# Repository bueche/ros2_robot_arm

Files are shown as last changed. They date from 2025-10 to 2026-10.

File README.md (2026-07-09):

# Ros2 Robot Arm and Balance PID Controller Using Koch v1.1 Follower

## Summary
The following repository has the source, resources, and instructions for building a robotic arm and its digital twin. The arm is based on a modified Koch V1.1 "follower arm" physical design (see [Robotis Koch v1.1 follower arm](https://robotis.us/koch-v1-1-low-cost-robot-arm-follower/)) and its powered by The Robot Operating System v2 [ROS2](https://github.com/ros2).  

(**NEW**) The current effort is focused on enabling this robotic arm to balance a cup containing a metal ball bearing. Balancing is a perennial challenge with robotics (as humanoid robots often fall at embarrassing times ;-)). The koch v1.1 hardware is a bit limited to explore all aspects of balance, but useful as a starter task. This is being 
accomplished by enhancing the robot with additinoal hardware (IMU sensor and inferencing camera) and software, including a Balance [PID controller](https://en.wikipedia.org/wiki/Proportional%E2%80%93integral%E2%80%93derivative_controller) (PID = Proportional–integral–derivative) and a vision ML model among other modules. [Learn more ..](./documentation/balance.md)

This branch supports Ros2 Jazzy (4.2+) and a combination with Humble for the ball bearing detection inferencing.

The details in this project include:
 - Fabrication and/or purchase, modification, and assembly of robotic parts (brackets, Dynamixel servos, and related circuit boards and sensors)
 - Testing and tuning of the physical robot
 - Creating, calibrating, and tuning of the robot arm digital twin (that runs in [rviz](https://docs.ros.org/en/jazzy/Tutorials/Intermediate/RViz/RViz-User-Guide/RViz-User-Guide.html)),
 - Refinement of ROS2-based software to support various actions of the robotic arm and the gathering of physical statistics (current, voltage, temperature, etc)
 - The development of the ML models for ball detection and the PID controller for for balance.

<p align="center">
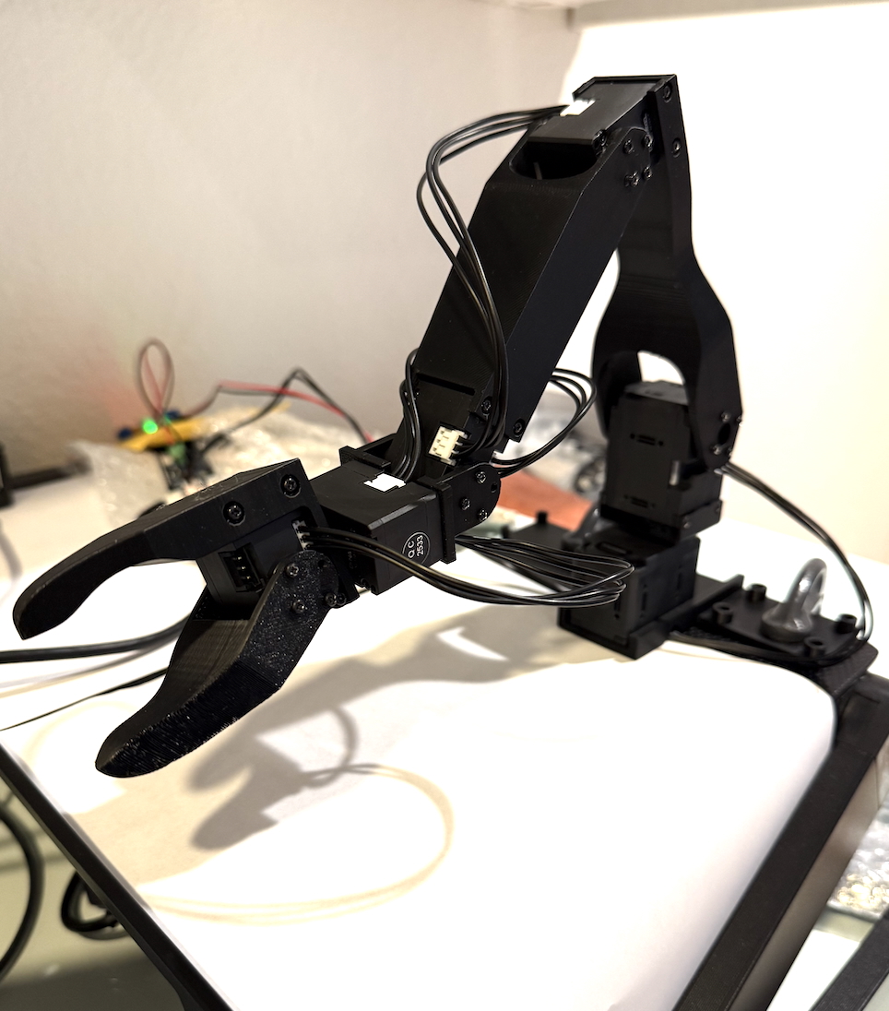
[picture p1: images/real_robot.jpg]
Real Robot Arm
  
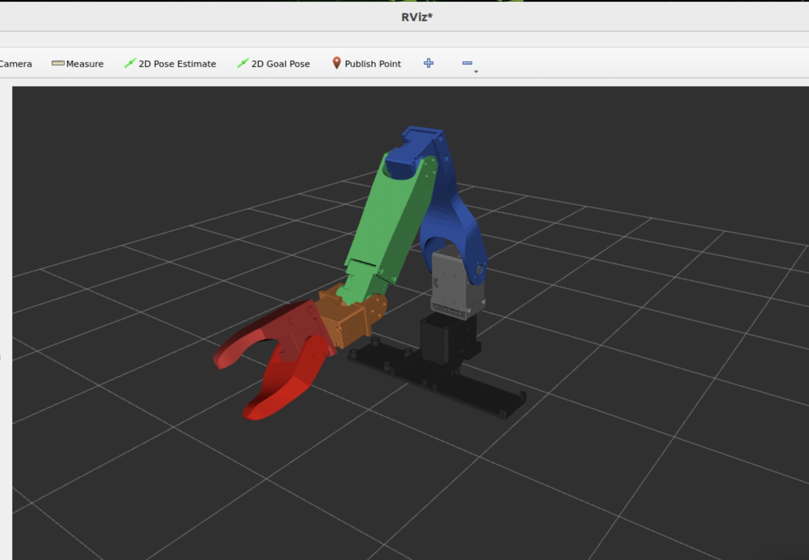
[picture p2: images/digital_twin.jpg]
The digital twin
  
</p>

The documentation for this repository covers the following:
- [Software Setup](./documentation/software_setup.md): how to create the docker envrionment and any additional setup commands. 
- [Hardware Setup](./documentation/hardware_setup.md): Although the setup of the koch_v11 physical robot (leader and follower arms) is partially documented ([Arm assembly by Jess Moss](https://www.youtube.com/watch?v=8nQIg9BwwTk)), those instructions lacked details on some of the required electrical setup. In addition, we are using different controller boards (e.g., Dynamixel OpenRB 150).
- [Firmware Setup and Configuration](./documentation/firmware.md): Notes on the firmware setup and configuration for the OpenRB 150, the servo motors, the current sensors, and the ESP32.
- [Notes on creating the digital twin](./documentation/digital_twin.md): A series of notes that cover the problems and solutions for creating the digital twin.
- [Launching the Physical Robot](./documentation/launching_physical.md) Steps involved in bringing up the physical robot.
- [Running the display only version of the Digital twin](./documentation/display_launch.md): This describes how to bring up the digital twin - either along side the physical robot or by itself as an rviz display-only flavor of the robot.
- [Pose Sequence Tools and Analysis](./documentation/utilities.md): Several tools are provided that drive the robot through a series of poses and analyze physical characteristics (position, temp, current, voltage, etc). This section also provides some analysis case studies that are of interest.
- **NEW** [Balancing a cup with the robotic arm ](./documentation/balance.md): These notes include detailed descriptions of the add-ons to the Koch v1.1 hardware (3D Inferencing camera and IMU) and software: PID related nodes and Machine Learning models for inferencing on the Camera and on an Nvidia Orin Nano.

<p align="center">
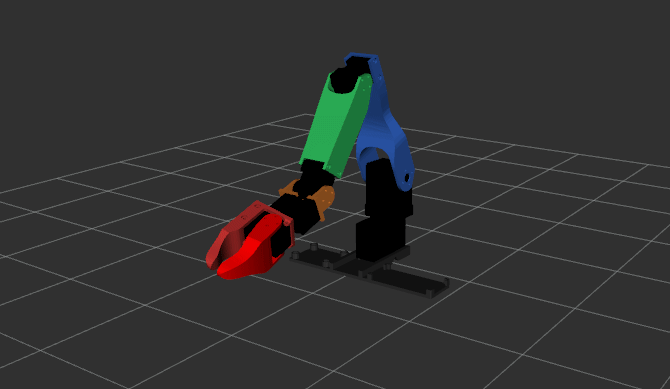
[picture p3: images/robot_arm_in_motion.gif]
Real Robot Arm
  
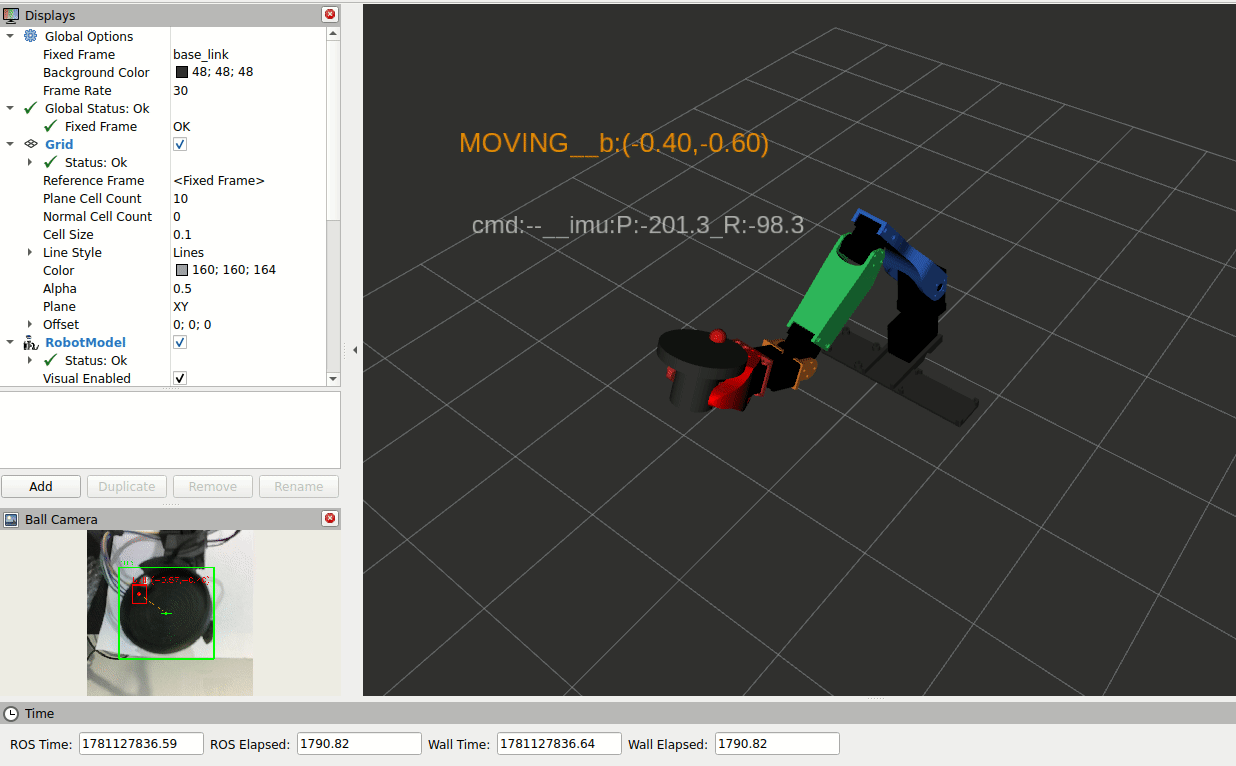
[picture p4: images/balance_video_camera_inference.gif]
balance video

</p>

Animations above:
1. The digital twin executing a series of poses that exercise all of the robotic joints.
2. The full rviz output showing a small excerpt of the pose and PID operations. The lower lefthand side is an bounding box annotated view of the camera (image after inferencing) and the right hand side 3D view shows the corresponding movement of the cup, ball, and robot. In this video 5 different tipping poses are set moving the ball bearing to one of the cup. Following each the balance pid controller kicks in and balances the ball within the cup.

## FAQ
### How can this repository be useful?
This repository can be of use to someone building robotics in several ways:
1. *Developers using the Koch V1.1 follower arm*: Although some of the design and operation of the Koch v1.1 robot arm is open source, a developer of it may encounter a number of gaps or issues when working with it. This repository should complement information and software from ROBOTIS and other sources. For example, we provide a  [koch v1.1 URDF](https://github.com/bueche/ros2_robot_arm/blob/main/writing_robot_description/urdf/koch_v11_arm_real.urdf) file that is configured and calibrated to provide a digital twin that matches the physical robot in appearance. In addition, we provide [complete and accurate wiring diagrams](https://github.com/bueche/ros2_robot_arm/blob/main/documentation/hardware_setup.md#electrical-notes) that detail how to co-exist the 12V and 5V Dynamixel servos in the same environment.
   
2. *Developers interested in PID controllers and balance*: Achieving balance in a robotics system has been a challenging research and development area. Humanoid robots still fall over regularly in critical demos. Although the koch v1.1 robot arm is limited in a number of ways the effort of getting it to balance a cup is a good starter task in this area.

3. *Developers integrating vision into their robotics system*: This is perhaps less challenging than achieving balance, but still difficult and covered in much detail. We explore inference on the camera vs. on an Nvidia Orin Nano.
 
4. *Developers wanting to pull more telemetry from Dynamixel servos in a ROS2 environment*: The ros2 interface for the Dynamixel servos is quite limited relative to the internal data it can pull (as compared with the Dynamixel Wizard tool). For example, one can't get a reading on the voltage seen by a servo, even though extra strain on the system could lead to an under-volt situation for the servos in series. We provide information on how to improve this for ros2 and how to set this up ([in code](https://github.com/bueche/ros2_robot_arm/blob/main/documentation/software_setup.md#dynamixel-software-changes)) and retrieve the values at runtime via ros2.

5. *Developers who are adapting robotic arms to ROS2 or not starting from a well defined kit*: ROBOTIS provides several full kits for someone getting started with robot arms that provide a good head start including this [Koch v1.1.](https://robotis.us/koch-v1-1-low-cost-robot-arm-follower/), [OMX AI manipulator](https://robotis.us/omx-ai-us/), [OMY AI manipulator](https://robotis.us/omy-ai3m/), and more. This project provides information for someone who is departing from an easy-to-assemble kit.

### What is a leader-follower robotic arm?
A leader-follower robotic arm system consists of two robotic manipulators where one arm (the leader) is manually controlled by a human operator, and the second arm (the follower) replicates those movements in real-time. It's essentially a form of bilateral teleoperation. In this project we are primarily focused on the follower arm.

### Why is this project focused on the follower?
In general leader arms are meant more for human manipulation as they define the poses that the follower will replicate. That limited operational scope for the leader means that its likely that the arm is under powered and/or has a design that is for human manipulation vs. automation. In this project we use the follower as the leader (to predefine poses and collect the measurements) albiet in a less automatic fashion. We also want to study the follower's load and physical characeteristics (e.g., temperature) as it repeatedly performs the activity. In addition, the cup balancing sub-project doesn't quite fit the leader/follower paradigm. 

## Upcoming sub-projects
### Upgrade of Nvidia Orin Nano to JetPack 7.2 with Jetson Linux 39.2
This upgrade to JetPack 7.2 with Jetson Linux 39.2 will allow this project to by-pass the inferencing on the camera and increase the frames per sec inferencing from 12 to 35 FPS. Aside from performance the benefit is an all Jazzy architecture with that approach.

### Extend the software to support the SO-arm101 and Feetech servos
This sub-project is about extending the software and hardware support to a different robotic arm the SO-ARM101 which is based on Feetech servos rather than Dynamixel servos. 

## Extend model to use 3D capabilities of OAK-D lite camera
Currently we are not using the 3D capabilities of the OAK-D lite camera due to its computational load on the camera. Once we have a Jazzy-based Nvidia inferencing stack, then this becomes something we can potentially leverage.

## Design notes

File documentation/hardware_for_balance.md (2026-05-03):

# Hardware for Cup Balancing Project

The additional hardware for this cup balancing portion of the project is identified in the [hardware section](./hardware_setup.md#balance-related-hardware). In this section we describe some key aspects of the two main additional components: the Luxonis Oak D camera and the IMU. 

## Camera: Luxonis OAK-D lite
In this section we discuss some points related to camera's and this application. 
- Introduction: As noted earlier the basic function of the camera is to track the movement and coordiates of the ball within the cup. It does this using hardware and software built into the camera. The camera is actually able to run a special trained ML model that has been built to recognize the cup and the ball moving in the robot environment. The goal is to get the ball to the middle of the cup and the ball is typically on the perimeter of the cup. Its current coordinates need to determined accurately and with low latency. 

<p align="center">
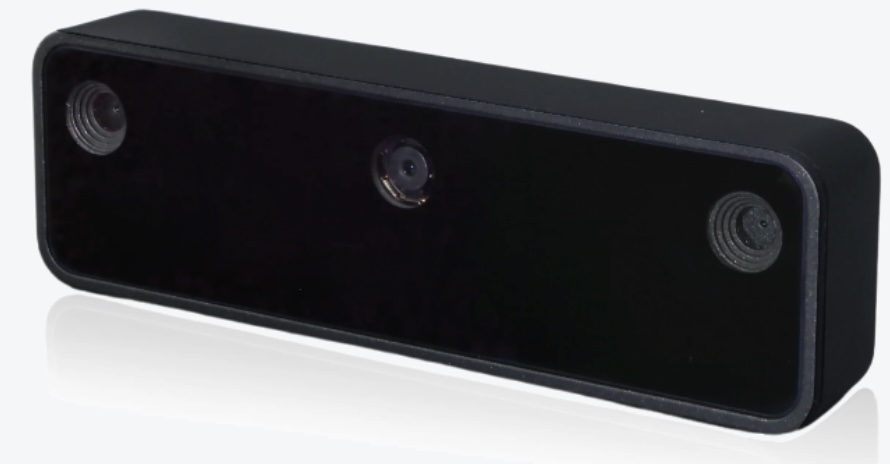
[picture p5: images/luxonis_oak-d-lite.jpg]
luxonis camera
  
</p>

- Inferencing camera vs. basic USB camera: 
  - *Why use an inferencing camera?* The basic flow requires that images are fed to a model which detects the cup and ball and provides the coordinates of the ball within the cup. The theoretically benefit of the inferencing camera is its ability to avoid having the transport those images in a high frame rate to the inferencing software running on a different host / processor. Instead the inferencing camera can do the detection locally and only report coordinates. It is ideal if all you have is a Raspberry Pi, but since we also have access to an Nvidia Orin Nano we have other options. We will implement the approach of using the Nvidia Orin Nano for inferencing, but have not done so as of yet. 
  
  Still, using the Nano as the camera attachmentWe did find that some additional tuning is required due to the fact that the Orin Nano (at least this version) only exposes USB-2 ports.
  ```
  nvidia-nano:~/robot_ws/src$ lsusb -t
   /:  Bus 02.Port 1: Dev 1, Class=root_hub, Driver=tegra-xusb/4p, 10000M
          |__ Port 1: Dev 2, If 0, Class=Hub, Driver=hub/4p, 10000M
   /:  Bus 01.Port 1: Dev 1, Class=root_hub, Driver=tegra-xusb/4p, 480M
          |__ Port 1: Dev 54, If 0, Class=Vendor Specific Class, Driver=, 480M <---- dev 54 at 480Mbps
          |__ Port 2: Dev 2, If 0, Class=Hub, Driver=hub/4p, 480M
          |__ Port 3: Dev 3, If 0, Class=Wireless, Driver=rtk_btusb, 12M
          |__ Port 3: Dev 3, If 1, Class=Wireless, Driver=rtk_btusb, 12M
  nvidia-nano:~/robot_ws/src$ lsusb
  Bus 002 Device 002: ID 0bda:0489 Realtek Semiconductor Corp. 4-Port USB 3.0 Hub
  Bus 002 Device 001: ID 1d6b:0003 Linux Foundation 3.0 root hub
  Bus 001 Device 003: ID 13d3:3549 IMC Networks Bluetooth Radio
  Bus 001 Device 002: ID 0bda:5489 Realtek Semiconductor Corp. 4-Port USB 2.0 Hub
  Bus 001 Device 054: ID 03e7:2485 Intel Movidius MyriadX <---------------- Luxonis Oak-D lite device 54
  Bus 001 Device 001: ID 1d6b:0002 Linux Foundation 2.0 root hub
  ```

  - *What is the USB-2 vs USB-3 bandwidth?*
    | Standard | Theoretical| Practical (60-70%) | 
    |----------|------------|--------------------|
    | USB 2.0 High Speed | 480 Mbps | ~300 Mbps | 
    | USB 3.0 SuperSpeed | 5000 Mbps | ~3000 Mbps |

  - *But is USB-2 a bottleneck?* With raw frames it will be.  
  - *What is an alternative approach to Camera inferencing?* Alternatively, 
  
  - We are motivated to reduce the image transport bandwidth partly because of Nvidia Orin Nano's USB-2 limitation. 
  - *Why does USB-2 have insufficient bandwidth for streaming video for this application?* The raw image bandwidth formula can be put as follows:
  ```
  bandwidth = image_width × image_height × channels × bytes_per_channel × frames_per_sec x jpeg_compression_factor
  ```
  - where:
    - image_width x image_height define the pixels/frame.
    - Ideally, we could process at least 30 frames per sec to ensure smooth/fluid movement as perceived by our eyes, but this rate has a signficant impact on bandwidth.
    - there are 3 channels of  ....
    - the compression factor is 1/15
  - USB bandwidth:
    | Standard | Theoretical| Practical (60-70%) | 
    |----------|------------|--------------------|
    | USB 2.0 High Speed | 480 Mbps | ~300 Mbps | 
    | USB 3.0 SuperSpeed | 5000 Mbps | ~3000 Mbps |

- Camera inferencing vs. Nvidia inferencing
  - Now we have been able to achieve 12 frames per sec cup/ball inferencing using the Luxonis OAK-D lite and a 640x640 YOLOv8n ML model. This is pretty close to with  [benchmark results for this device](https://docs.luxonis.com/hardware/platform/rvc/rvc2/) which reached 14.3 frames per sec inferencing. 
  - The reported inference latency in that Luxonis benchmark was 120 msec. We expect to get significantly better latency using Nvidia as long as the USB-2 pipe doesn't become a bottleneck when we leverage the  H.264 or H.265 codecs.
  
- 3D camera vs. 2D camera
  - The Luxonis OAK-D lite is also a 3D camera. We have turned off that capability due to the processing needs of inferencing, but will re-enable it when inferencing shifts to the Nvidia Orin Nano.

## IMU
Some discussion points on IMU:
- IMU level vs. ball level
- IMU calibration challenges
- IMU wiring impact on servo accuracy and mobility 
- also reference the Dynamixel servo tuning section

<p align="center">
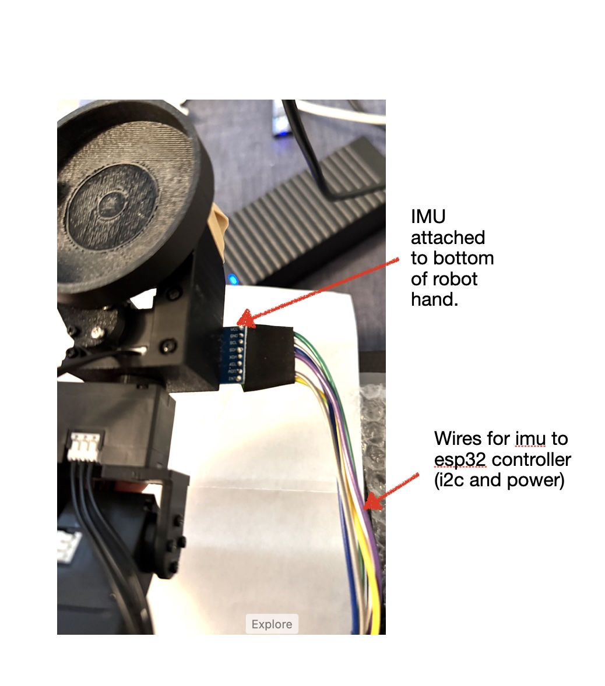
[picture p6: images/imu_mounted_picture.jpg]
imu mounted on bottom of hand
  
</p>

Discussion on the Koch v1.1 and:
- its ability to hold a cup steady
- its ability to hold a cup + ball + IMU + wires for IMU

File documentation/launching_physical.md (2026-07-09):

# Launching the Physical Robot 

Once the software and hardware envionment has been setup with the one-time setup items, then a few additional commands are needed to bring up the physical robot and its digital twin in Rviz2.

## Table of Contents
- [Ensure that the USB port can be accessed](#ensure-that-the-usb-port-can-be-accessed)
- [Launching the basic robot](#launch-the-robot-via-ros2)
- [Launching the robot for balancing activity](#launcing-the-robot-for-balancing-activity)

## Ensure that the USB port can be accessed
The code assumes the port is `/dev/ttyUSB0`. On a Raspberry Pi5 on Ubuntu the device is either `/dev/ttyACM0` or `/dev/ttyACM0`.
If the there is no ttyUSB0 then create a soft link to it.
On ubuntu:

```bash
$ ls -lt /dev/tty* | head -5
crw-rw-rw- 1 root   tty       5,   0 Dec 24 10:44 /dev/tty
crw-rw---- 1 root   dialout 166,   0 Dec 24 10:43 /dev/ttyACM0   
crw--w---- 1 bueche tty       4,   2 Nov 10 14:28 /dev/tty2
crw------- 1 root   root      3, 167 Nov 10 14:27 /dev/ttyz7
rpi5:~$
rpi5:~$ sudo ln -sf /dev/ttyACM0 /dev/ttyUSB0
rpi5:~$
rpi5:~$ ls -lt /dev/tty* | head -5
crw-rw-rw- 1 root   tty       5,   0 Dec 24 10:44 /dev/tty
crw-rw---- 1 root   dialout 166,   0 Dec 24 10:43 /dev/ttyACM0   
lrwxrwxrwx 1 root   root          12 Dec 21 18:35 /dev/ttyUSB0 -> /dev/ttyACM0 # SOFT LINK CREATED
crw--w---- 1 bueche tty       4,   2 Nov 10 14:28 /dev/tty2
crw------- 1 root   root      3, 167 Nov 10 14:27 /dev/ttyz7
```
But it still needs to be readable and writable by other.

On ubuntu:
```bash
rpi5:~$ ls -lt /dev/tty* | head -5
crw-rw-rw- 1 root   tty       5,   0 Dec 24 10:44 /dev/tty
crw-rw---- 1 root   dialout 166,   0 Dec 24 10:43 /dev/ttyACM0   # NOTE: IS NOT rw BY other
lrwxrwxrwx 1 root   root          12 Dec 21 18:35 /dev/ttyUSB0 -> /dev/ttyACM0
crw--w---- 1 bueche tty       4,   2 Nov 10 14:28 /dev/tty2
crw------- 1 root   root      3, 167 Nov 10 14:27 /dev/ttyz7

rpi5:~$ sudo chmod ugo+rw /dev/ttyACM0

rpi5:~$ ls -lt /dev/tty* | head -5
crw-rw-rw- 1 root   tty       5,   0 Dec 24 11:44 /dev/tty
crw-rw-rw- 1 root   dialout 166,   0 Dec 24 10:47 /dev/ttyACM0 # NOTES: NOW rw BY other
lrwxrwxrwx 1 root   root          12 Dec 21 18:35 /dev/ttyUSB0 -> /dev/ttyACM0
crw--w---- 1 bueche tty       4,   2 Nov 10 14:28 /dev/tty2
crw------- 1 root   root      3, 167 Nov 10 14:27 /dev/ttyz7

```

## Launch the robot via ros2
```bash
rpi5:~/$ 
rpi5:~/$ pwd
/home/ubuntu/
rpi5:~/$ cd robot_ws
rpi5:~/robot_ws$ source ./install/setup.bash
rpi5:~/robot_ws$ ros2 launch writing_robot_description koch_v11_real_robot.launch.py
```
This will launch the ros2 robot software. The full example output is shown below. We comment on some of parts below.

```
$ ros2 launch writing_robot_description koch_v11_real_robot.launch.py
[INFO] [launch]: All log files can be found below /home/ubuntu/.ros/log/2026-03-01-23-27-25-361593-bueche-rpi5-6584
[INFO] [launch]: Default logging verbosity is set to INFO
[INFO] [robot_state_publisher-1]: process started with pid [6587]
[INFO] [ros2_control_node-2]: process started with pid [6588]
[ros2_control_node-2] [INFO] [1772407645.679930506] [controller_manager]: Using Steady (Monotonic) clock for triggering controller manager cycles.
[ros2_control_node-2] [INFO] [1772407645.686064407] [controller_manager]: Subscribing to '/robot_description' topic for robot description.
[ros2_control_node-2] [INFO] [1772407645.690637597] [controller_manager]: update rate is 100 Hz
[ros2_control_node-2] [INFO] [1772407645.690681912] [controller_manager]: Overruns handling is : enabled
[ros2_control_node-2] [INFO] [1772407645.690695190] [controller_manager]: Spawning controller_manager RT thread with scheduler priority: 50
[ros2_control_node-2] [WARN] [1772407645.690820061] [controller_manager]: Could not enable FIFO RT scheduling policy: with error number <1>(Operation not permitted). See [https://control.ros.org/master/doc/ros2_control/controller_manager/doc/userdoc.html] for details on how to enable realtime scheduling.
[robot_state_publisher-1] [WARN] [1772407645.709807044] [kdl_parser]: The root link base_link has an inertia specified in the URDF, but KDL does not support a root link with an inertia.  As a workaround, you can add an extra dummy link to your URDF.
[robot_state_publisher-1] [INFO] [1772407645.710002990] [robot_state_publisher]: Robot initialized
[ros2_control_node-2] [INFO] [1772407645.781235642] [controller_manager]: Received robot description from topic.
[ros2_control_node-2] [INFO] [1772407645.787500822] [controller_manager]: Loading hardware 'koch_v11_system' 
[ros2_control_node-2] [INFO] [1772407645.802065987] [controller_manager]: Loaded hardware 'koch_v11_system' from plugin 'dynamixel_hardware_interface/DynamixelHardware'
[ros2_control_node-2] [INFO] [1772407645.803658458] [controller_manager]: Initialize hardware 'koch_v11_system' 
[ros2_control_node-2] transmission_to_joint_matrix_ 
[ros2_control_node-2] [0][0] 1.000000, [0][1] 0.000000, [0][2] 0.000000, [0][3] 0.000000, [0][4] 0.000000, [0][5] 0.000000, 
[ros2_control_node-2] [1][0] 0.000000, [1][1] 1.000000, [1][2] 0.000000, [1][3] 0.000000, [1][4] 0.000000, [1][5] 0.000000, 
[ros2_control_node-2] [2][0] 0.000000, [2][1] 0.000000, [2][2] 1.000000, [2][3] 0.000000, [2][4] 0.000000, [2][5] 0.000000, 
[ros2_control_node-2] [3][0] 0.000000, [3][1] 0.000000, [3][2] 0.000000, [3][3] 1.000000, [3][4] 0.000000, [3][5] 0.000000, 
[ros2_control_node-2] [4][0] 0.000000, [4][1] 0.000000, [4][2] 0.000000, [4][3] 0.000000, [4][4] 1.000000, [4][5] 0.000000, 
[ros2_control_node-2] [5][0] 0.000000, [5][1] 0.000000, [5][2] 0.000000, [5][3] 0.000000, [5][4] 0.000000, [5][5] 1.000000, 
[ros2_control_node-2] joint_to_transmission_matrix_ 
[ros2_control_node-2] [0][0] 1.000000, [0][1] 0.000000, [0][2] 0.000000, [0][3] 0.000000, [0][4] 0.000000, [0][5] 0.000000, 
[ros2_control_node-2] [1][0] 0.000000, [1][1] 1.000000, [1][2] 0.000000, [1][3] 0.000000, [1][4] 0.000000, [1][5] 0.000000, 
[ros2_control_node-2] [2][0] 0.000000, [2][1] 0.000000, [2][2] 1.000000, [2][3] 0.000000, [2][4] 0.000000, [2][5] 0.000000, 
[ros2_control_node-2] [3][0] 0.000000, [3][1] 0.000000, [3][2] 0.000000, [3][3] 1.000000, [3][4] 0.000000, [3][5] 0.000000, 
[ros2_control_node-2] [4][0] 0.000000, [4][1] 0.000000, [4][2] 0.000000, [4][3] 0.000000, [4][4] 1.000000, [4][5] 0.000000, 
[ros2_control_node-2] [5][0] 0.000000, [5][1] 0.000000, [5][2] 0.000000, [5][3] 0.000000, [5][4] 0.000000, [5][5] 1.000000, 
[ros2_control_node-2] [INFO] [1772407645.818822442] [dynamixel_hardware_interface]: error_timeout_ms parameter not found, using default value of 500ms
[ros2_control_node-2] [INFO] [1772407645.818887646] [dynamixel_hardware_interface]: If there is a torque enabled Dynamixel, the program will be terminated. Set 'disable_torque_at_init' parameter to 'true' to disable torque at initialization.
[ros2_control_node-2] [INFO] [1772407645.818910035] [dynamixel_hardware_interface]: port_name /dev/ttyUSB0 / baudrate 1000000
[ros2_control_node-2] Dynamixel Information File List.
[ros2_control_node-2] num: 30, name: mx_28.model
[ros2_control_node-2] num: 220, name: omy_hat.model
[ros2_control_node-2] num: 230, name: omy_end.model
[ros2_control_node-2] num: 231, name: omy_end_rh_p12_rn.model
[ros2_control_node-2] num: 260, name: hx5_d20_rr.model
[ros2_control_node-2] num: 261, name: hx5_d20_rl.model
[ros2_control_node-2] num: 6001, name: hx5_d20_r_synctable_1_device_1.model
[ros2_control_node-2] num: 6002, name: hx5_d20_r_synctable_1_device_2.model
[ros2_control_node-2] num: 6003, name: hx5_d20_r_synctable_1_device_3.model
[ros2_control_node-2] num: 6004, name: hx5_d20_r_synctable_1_device_4.model
[ros2_control_node-2] num: 6005, name: hx5_d20_r_synctable_1_device_5.model
[ros2_control_node-2] num: 6006, name: hx5_d20_r_synctable_2_device_1.model
[ros2_control_node-2] num: 6007, name: hx5_d20_r_synctable_2_device_2.model
[ros2_control_node-2] num: 6008, name: hx5_d20_r_synctable_2_device_3.model
[ros2_control_node-2] num: 6009, name: hx5_d20_r_synctable_2_device_4.model
[ros2_control_node-2] num: 6010, name: hx5_d20_r_synctable_2_device_5.model
[ros2_control_node-2] num: 6011, name: hx5_d20_r_synctable_3_device_1.model
[ros2_control_node-2] num: 6012, name: hx5_d20_r_synctable_3_device_2.model
[ros2_control_node-2] num: 6013, name: hx5_d20_r_synctable_3_device_3.model
[ros2_control_node-2] num: 6014, name: hx5_d20_r_synctable_3_device_4.model
[ros2_control_node-2] num: 6015, name: hx5_d20_r_synctable_3_device_5.model
[ros2_control_node-2] num: 6016, name: hx5_d20_r_synctable_4_device_1.model
[ros2_control_node-2] num: 6017, name: hx5_d20_r_synctable_4_device_2.model
[ros2_control_node-2] num: 6018, name: hx5_d20_r_synctable_4_device_3.model
[ros2_control_node-2] num: 6019, name: hx5_d20_r_synctable_4_device_4.model
[ros2_control_node-2] num: 6020, name: hx5_d20_r_synctable_4_device_5.model
[ros2_control_node-2] num: 6021, name: hx5_d20_r_synctable_5_device_1.model
[ros2_control_node-2] num: 6022, name: hx5_d20_r_synctable_5_device_2.model
[ros2_control_node-2] num: 6023, name: hx5_d20_r_synctable_5_device_3.model
[ros2_control_node-2] num: 6024, name: hx5_d20_r_synctable_5_device_4.model
[ros2_control_node-2] num: 6025, name: hx5_d20_r_synctable_5_device_5.model
[ros2_control_node-2] num: 311, name: mx_64.model
[ros2_control_node-2] num: 321, name: mx_106.model
[ros2_control_node-2] num: 350, name: xl320.model
[ros2_control_node-2] num: 536, name: sensorxel_joy.model
[ros2_control_node-2] num: 537, name: ffw_g40_imu.model
[ros2_control_node-2] num: 600, name: sensorxel_joy.model
[ros2_control_node-2] num: 601, name: ffw_g10_led.model
[ros2_control_node-2] num: 602, name: ffw_g10_rcu.model
[ros2_control_node-2] num: 620, name: ffw_sg2_steer_1.model
[ros2_control_node-2] num: 621, name: ffw_sg2_steer_2.model
[ros2_control_node-2] num: 622, name: ffw_sg2_steer_3.model
[ros2_control_node-2] num: 623, name: ffw_sg2_drive_1.model
[ros2_control_node-2] num: 624, name: ffw_sg2_drive_2.model
[ros2_control_node-2] num: 625, name: ffw_sg2_drive_3.model
[ros2_control_node-2] num: 1000, name: xh430_w350.model
[ros2_control_node-2] num: 1001, name: xd430_t350.model
[ros2_control_node-2] num: 1010, name: xh430_w210.model
[ros2_control_node-2] num: 1011, name: xd430_t210.model
[ros2_control_node-2] num: 1020, name: xm430_w350.model
[ros2_control_node-2] num: 1030, name: xm430_w210.model
[ros2_control_node-2] num: 1040, name: xh430_v350.model
[ros2_control_node-2] num: 1050, name: xh430_v210.model
[ros2_control_node-2] num: 1060, name: xl430_w250.model
[ros2_control_node-2] num: 1070, name: xc430_w150.model
[ros2_control_node-2] num: 1070, name: xc430_w150.model
[ros2_control_node-2] num: 1080, name: xc430_w240.model
[ros2_control_node-2] num: 1080, name: xc430_w240.model
[ros2_control_node-2] num: 1090, name: 2xl430_w250.model
[ros2_control_node-2] num: 1100, name: xh540_w270.model
[ros2_control_node-2] num: 1101, name: xd540_t270.model
[ros2_control_node-2] num: 1110, name: xh540_w150.model
[ros2_control_node-2] num: 1111, name: xd540_t150.model
[ros2_control_node-2] num: 1120, name: xm540_w270.model
[ros2_control_node-2] num: 1130, name: xm540_w150.model
[ros2_control_node-2] num: 1140, name: xh540_v270.model
[ros2_control_node-2] num: 1150, name: xh540_v150.model
[ros2_control_node-2] num: 1160, name: 2xc430_w250.model
[ros2_control_node-2] num: 1170, name: xw540_t260.model
[ros2_control_node-2] num: 1180, name: xw540_t140.model
[ros2_control_node-2] num: 1190, name: xl330_m077.model
[ros2_control_node-2] num: 1200, name: xl330_m288.model
[ros2_control_node-2] num: 1210, name: xc330_t181.model
[ros2_control_node-2] num: 1220, name: xc330_t288.model
[ros2_control_node-2] num: 1230, name: xc330_m181.model
[ros2_control_node-2] num: 1240, name: xc330_m288.model
[ros2_control_node-2] num: 1270, name: xw430_t333.model
[ros2_control_node-2] num: 1310, name: xw540_h260.model
[ros2_control_node-2] num: 1700, name: xc335_t332.model
[ros2_control_node-2] num: 2000, name: ph42_020_s300.model
[ros2_control_node-2] num: 2010, name: ph54_100_s500.model
[ros2_control_node-2] num: 2020, name: ph54_200_s500.model
[ros2_control_node-2] num: 2100, name: pm42_010_s260.model
[ros2_control_node-2] num: 2110, name: pm54_040_s250.model
[ros2_control_node-2] num: 2120, name: pm54_060_s250.model
[ros2_control_node-2] num: 4000, name: ym070_210_m001.model
[ros2_control_node-2] num: 4010, name: ym070_210_b001.model
[ros2_control_node-2] num: 4020, name: ym070_210_r051.model
[ros2_control_node-2] num: 4030, name: ym070_210_r099.model
[ros2_control_node-2] num: 4040, name: ym070_210_a051.model
[ros2_control_node-2] num: 4050, name: ym070_210_a099.model
[ros2_control_node-2] num: 4120, name: ym080_230_m001.model
[ros2_control_node-2] num: 4130, name: ym080_230_b001.model
[ros2_control_node-2] num: 4140, name: ym080_230_r051.model
[ros2_control_node-2] num: 4150, name: ym080_230_r099.model
[ros2_control_node-2] num: 4160, name: ym080_230_a051.model
[ros2_control_node-2] num: 4170, name: ym080_230_a099.model
[ros2_control_node-2] num: 35074, name: rh_p12_rn.model
[ros2_control_node-2] num: 43289, name: m42_10_s260_ra.model
[ros2_control_node-2] num: 46097, name: m54_40_s250_ra.model
[ros2_control_node-2] num: 46353, name: m54_60_s250_ra.model
[ros2_control_node-2] num: 51201, name: h42_20_s300_ra.model
[ros2_control_node-2] num: 53769, name: h54_100_s500_ra.model
[ros2_control_node-2] num: 54025, name: h54_200_s500_ra.model
[ros2_control_node-2] [INFO] [1772407645.819989522] [dynamixel_hardware_interface]: $$$$$$$$$$$$$$$$$$$$$$$$$$$$$$$$$$$$$$$$
[ros2_control_node-2] [INFO] [1772407645.820040651] [dynamixel_hardware_interface]: $$$$$ Init Dxl Comm Port
[ros2_control_node-2] Succeeded to open the port [/dev/ttyUSB0]! (attempt 1/5)
[ros2_control_node-2] Succeeded to change the baudrate [1000000]!
[ros2_control_node-2] [comm_id:001][ID:001] Request ping	 - Ping succeeded. Dynamixel model number : 1060 (xl430_w250.model)
[ros2_control_node-2] [InitTorqueStates][comm_id:001][ID:001] Current torque state: OFF
[ros2_control_node-2] [comm_id:002][ID:002] Request ping	 - Ping succeeded. Dynamixel model number : 1060 (xl430_w250.model)
[ros2_control_node-2] [InitTorqueStates][comm_id:002][ID:002] Current torque state: OFF
[ros2_control_node-2] [comm_id:003][ID:003] Request ping	 - Ping succeeded. Dynamixel model number : 1200 (xl330_m288.model)
[ros2_control_node-2] [InitTorqueStates][comm_id:003][ID:003] Current torque state: OFF
[ros2_control_node-2] [comm_id:004][ID:004] Request ping	 - Ping succeeded. Dynamixel model number : 1200 (xl330_m288.model)
[ros2_control_node-2] [InitTorqueStates][comm_id:004][ID:004] Current torque state: OFF
[ros2_control_node-2] [comm_id:005][ID:005] Request ping	 - Ping succeeded. Dynamixel model number : 1200 (xl330_m288.model)
[ros2_control_node-2] [InitTorqueStates][comm_id:005][ID:005] Current torque state: OFF
[ros2_control_node-2] [comm_id:006][ID:006] Request ping	 - Ping succeeded. Dynamixel model number : 1190 (xl330_m077.model)
[ros2_control_node-2] [InitTorqueStates][comm_id:006][ID:006] Current torque state: OFF
[ros2_control_node-2] [INFO] [1772407645.889421591] [dynamixel_hardware_interface]: $$$$$ Init Dxl Read Items
[ros2_control_node-2] Dynamixel Read Type : bulk read
[ros2_control_node-2] ID : 1	Read items : 	Present Position	Present Velocity	Present Load	Present Temperature	Present Input Voltage
[ros2_control_node-2] ID : 2	Read items : 	Present Position	Present Velocity	Present Load	Present Temperature	Present Input Voltage
[ros2_control_node-2] ID : 3	Read items : 	Present Position	Present Velocity	Present Current	Present Temperature	Present Input Voltage
[ros2_control_node-2] ID : 4	Read items : 	Present Position	Present Velocity	Present Current	Present Temperature	Present Input Voltage
[ros2_control_node-2] ID : 5	Read items : 	Present Position	Present Velocity	Present Current	Present Temperature	Present Input Voltage
[ros2_control_node-2] ID : 6	Read items : 	Present Position	Present Velocity	Present Current	Present Temperature	Present Input Voltage
[ros2_control_node-2] [ID:001] Add Indirect Address Read Item : [Present Position]
[ros2_control_node-2] [ID:001] Add Indirect Address Read Item : [Present Velocity]
[ros2_control_node-2] [ID:001] Add Indirect Address Read Item : [Present Load]
[ros2_control_node-2] [ID:001] Add Indirect Address Read Item : [Present Temperature]
[ros2_control_node-2] [ID:001] Add Indirect Address Read Item : [Present Input Voltage]
[ros2_control_node-2] [ID:002] Add Indirect Address Read Item : [Present Position]
[ros2_control_node-2] [ID:002] Add Indirect Address Read Item : [Present Velocity]
[ros2_control_node-2] [ID:002] Add Indirect Address Read Item : [Present Load]
[ros2_control_node-2] [ID:002] Add Indirect Address Read Item : [Present Temperature]
[ros2_control_node-2] [ID:002] Add Indirect Address Read Item : [Present Input Voltage]
[ros2_control_node-2] [ID:003] Add Indirect Address Read Item : [Present Position]
[ros2_control_node-2] [ID:003] Add Indirect Address Read Item : [Present Velocity]
[ros2_control_node-2] [ID:003] Add Indirect Address Read Item : [Present Current]
[ros2_control_node-2] [ID:003] Add Indirect Address Read Item : [Present Temperature]
[ros2_control_node-2] [ID:003] Add Indirect Address Read Item : [Present Input Voltage]
[ros2_control_node-2] [ID:004] Add Indirect Address Read Item : [Present Position]
[ros2_control_node-2] [ID:004] Add Indirect Address Read Item : [Present Velocity]
[ros2_control_node-2] [ID:004] Add Indirect Address Read Item : [Present Current]
[ros2_control_node-2] [ID:004] Add Indirect Address Read Item : [Present Temperature]
[ros2_control_node-2] [ID:004] Add Indirect Address Read Item : [Present Input Voltage]
[ros2_control_node-2] [ID:005] Add Indirect Address Read Item : [Present Position]
[ros2_control_node-2] [ID:005] Add Indirect Address Read Item : [Present Velocity]
[ros2_control_node-2] [ID:005] Add Indirect Address Read Item : [Present Current]
[ros2_control_node-2] [ID:005] Add Indirect Address Read Item : [Present Temperature]
[ros2_control_node-2] [ID:005] Add Indirect Address Read Item : [Present Input Voltage]
[ros2_control_node-2] [ID:006] Add Indirect Address Read Item : [Present Position]
[ros2_control_node-2] [ID:006] Add Indirect Address Read Item : [Present Velocity]
[ros2_control_node-2] [ID:006] Add Indirect Address Read Item : [Present Current]
[ros2_control_node-2] [ID:006] Add Indirect Address Read Item : [Present Temperature]
[ros2_control_node-2] [ID:006] Add Indirect Address Read Item : [Present Input Voltage]
[ros2_control_node-2] set fast bulk read (indirect addr) : addr 634, size 13
[ros2_control_node-2] set fast bulk read (indirect addr) : addr 634, size 13
[ros2_control_node-2] set fast bulk read (indirect addr) : addr 230, size 13
[ros2_control_node-2] set fast bulk read (indirect addr) : addr 230, size 13
[ros2_control_node-2] set fast bulk read (indirect addr) : addr 230, size 13
[ros2_control_node-2] set fast bulk read (indirect addr) : addr 230, size 13
[ros2_control_node-2] [ID:001] Add BulkRead item : [Indirect Item Data][634][13]
[ros2_control_node-2] [ID:002] Add BulkRead item : [Indirect Item Data][634][13]
[ros2_control_node-2] [ID:003] Add BulkRead item : [Indirect Item Data][230][13]
[ros2_control_node-2] [ID:004] Add BulkRead item : [Indirect Item Data][230][13]
[ros2_control_node-2] [ID:005] Add BulkRead item : [Indirect Item Data][230][13]
[ros2_control_node-2] [ID:006] Add BulkRead item : [Indirect Item Data][230][13]
[ros2_control_node-2] FastBulkRead handler set up successfully.
[ros2_control_node-2] Success to set BulkRead handler using indirect address
[ros2_control_node-2] [INFO] [1772407646.032963679] [dynamixel_hardware_interface]: $$$$$ Init Dxl Write Items
[ros2_control_node-2] Dynamixel Write Type : sync write
[ros2_control_node-2] ID : 1, 2, 3, 4, 5, 6, 
[ros2_control_node-2] Write items : 	Goal Position
[ros2_control_node-2] set sync write (indirect addr) : addr 224, size 4
[ros2_control_node-2] Success to set SyncWrite handler using indirect address
[ros2_control_node-2] [INFO] [1772407646.088268549] [controller_manager]: Successful initialization of hardware 'koch_v11_system'
[ros2_control_node-2] [INFO] [1772407646.089759389] [resource_manager]: 'configure' hardware 'koch_v11_system' 
[ros2_control_node-2] [INFO] [1772407646.089791723] [resource_manager]: Successful 'configure' of hardware 'koch_v11_system'
[ros2_control_node-2] [INFO] [1772407646.089814186] [resource_manager]: 'activate' hardware 'koch_v11_system' 
[ros2_control_node-2] [INFO] [1772407646.094021670] [dynamixel_hardware_interface]: Sync joint state to command (joint: shoulder_pan, position, 1.56313 <- position, 1.56313
[ros2_control_node-2] [INFO] [1772407646.094076893] [dynamixel_hardware_interface]: Sync joint state to command (joint: shoulder_lift, position, 2.71515 <- position, 2.71515
[ros2_control_node-2] [INFO] [1772407646.094095541] [dynamixel_hardware_interface]: Sync joint state to command (joint: elbow_flex, position, 1.77482 <- position, 1.77482
[ros2_control_node-2] [INFO] [1772407646.094112671] [dynamixel_hardware_interface]: Sync joint state to command (joint: wrist_flex, position, 0.895845 <- position, 0.895845
[ros2_control_node-2] [INFO] [1772407646.094128745] [dynamixel_hardware_interface]: Sync joint state to command (joint: wrist_roll, position, 1.56159 <- position, 1.56159
[ros2_control_node-2] [INFO] [1772407646.094144930] [dynamixel_hardware_interface]: Sync joint state to command (joint: pen_holder, position, 1.62142 <- position, 1.62142
[ros2_control_node-2] [INFO] [1772407646.094361209] [dynamixel_hardware_interface]: Enabling torque for Dynamixels
[ros2_control_node-2] [comm_id:001][ID:001] Torque ON
[ros2_control_node-2] [comm_id:002][ID:002] Torque ON
[ros2_control_node-2] [comm_id:003][ID:003] Torque ON
[ros2_control_node-2] [comm_id:004][ID:004] Torque ON
[ros2_control_node-2] [comm_id:005][ID:005] Torque ON
[ros2_control_node-2] [comm_id:006][ID:006] Torque ON
[ros2_control_node-2] [INFO] [1772407646.108393835] [dynamixel_hardware_interface]: Dynamixel Hardware Start!
[ros2_control_node-2] [INFO] [1772407646.108474039] [resource_manager]: Successful 'activate' of hardware 'koch_v11_system'
[ros2_control_node-2] [INFO] [1772407646.108612113] [controller_manager]: Registering statistics for : koch_v11_system
[ros2_control_node-2] [INFO] [1772407646.108785466] [controller_manager]: Resource Manager has been successfully initialized. Starting Controller Manager services...
[INFO] [spawner-3]: process started with pid [6624]
[spawner-3] [INFO] [1772407648.214204665] [spawner_joint_state_broadcaster]: waiting for service /controller_manager/list_controllers to become available...
[ros2_control_node-2] [INFO] [1772407648.222263297] [controller_manager]: Loading controller : 'joint_state_broadcaster' of type 'joint_state_broadcaster/JointStateBroadcaster'
[ros2_control_node-2] [INFO] [1772407648.222330113] [controller_manager]: Loading controller 'joint_state_broadcaster'
[ros2_control_node-2] [INFO] [1772407648.238686880] [controller_manager]: Controller 'joint_state_broadcaster' node arguments: --ros-args --params-file /tmp/launch_params_yroe8zdt 
[spawner-3] [INFO] [1772407648.267153504] [spawner_joint_state_broadcaster]: Loaded joint_state_broadcaster
[ros2_control_node-2] [INFO] [1772407648.269032328] [controller_manager]: Configuring controller: 'joint_state_broadcaster'
[ros2_control_node-2] [INFO] [1772407648.269240977] [joint_state_broadcaster]: 'joints' or 'interfaces' parameter is empty. All available state interfaces will be published
[ros2_control_node-2] [INFO] [1772407648.287854144] [controller_manager]: Activating controllers: [ joint_state_broadcaster ]
[ros2_control_node-2] [INFO] [1772407648.295436664] [controller_manager]: Successfully switched controllers!
[spawner-3] [INFO] [1772407648.307639576] [spawner_joint_state_broadcaster]: Configured and activated joint_state_broadcaster
[INFO] [spawner-3]: process has finished cleanly [pid 6624]
[INFO] [spawner-4]: process started with pid [6641]
[spawner-4] [INFO] [1772407650.225252761] [spawner_koch_v11_controller]: waiting for service /controller_manager/list_controllers to become available...
[spawner-4] [INFO] [1772407650.492474802] [spawner_koch_v11_controller]: Setting controller param "params_file" to "['/home/ubuntu/robot_ws/install/writing_robot_description/share/writing_robot_description/config/koch_v11_controllers_real.yaml']" for koch_v11_controller
[ros2_control_node-2] [INFO] [1772407650.502698982] [controller_manager]: Loading controller : 'koch_v11_controller' of type 'joint_trajectory_controller/JointTrajectoryController'
[ros2_control_node-2] [INFO] [1772407650.502751779] [controller_manager]: Loading controller 'koch_v11_controller'
[ros2_control_node-2] [INFO] [1772407650.513313313] [controller_manager]: Controller 'koch_v11_controller' node arguments: --ros-args --params-file /tmp/launch_params_yroe8zdt --params-file /home/ubuntu/robot_ws/install/writing_robot_description/share/writing_robot_description/config/koch_v11_controllers_real.yaml 
[spawner-4] [INFO] [1772407650.547436799] [spawner_koch_v11_controller]: Loaded koch_v11_controller
[ros2_control_node-2] [INFO] [1772407650.549255364] [controller_manager]: Configuring controller: 'koch_v11_controller'
[ros2_control_node-2] [INFO] [1772407650.549608347] [koch_v11_controller]: No specific joint names are used for command interfaces. Using 'joints' parameter.
[ros2_control_node-2] [INFO] [1772407650.549662384] [koch_v11_controller]: Command interfaces are [position] and state interfaces are [position velocity].
[ros2_control_node-2] [INFO] [1772407650.549714199] [koch_v11_controller]: Using 'splines' interpolation method.
[ros2_control_node-2] [INFO] [1772407650.553734645] [koch_v11_controller]: Action status changes will be monitored at 20.00 Hz.
[ros2_control_node-2] [INFO] [1772407650.567711919] [controller_manager]: Activating controllers: [ koch_v11_controller ]
[ros2_control_node-2] [INFO] [1772407650.575641718] [controller_manager]: Successfully switched controllers!
[spawner-4] [INFO] [1772407650.587938187] [spawner_koch_v11_controller]: Configured and activated koch_v11_controller
[INFO] [spawner-4]: process has finished cleanly [pid 6641]

```
## Launcing the robot for balancing activity
In this section we cover how to launch all of the ROS2 nodes for the balancing activity. This currently involves a number of terminal windows and we will at some point simplify it.

First, in the current setup some of the nodes run on the RPI5 and some on the Nvidia Orin Nano. 

### Step 1: Start up ball detector node on Nvidia Nano
This particular node and its parameters has been documented[here](./ball_detector.md). This is useful to start first as camera placement and lighting can greatly impact the detection process. An example invocation is shown below.
```
ubuntu@bueche-nvidia-nano:~/robot_ws/src$ ros2 run balance ball_detector_nvidia   --ros-args   -p engine_path:=/home/ubuntu/robot_ws/src/balance/models/ball_detector_v4.engine   -p input_size:=640   -p conf_threshold:=0.30   -p rgb_fps:=35
[INFO] [1777504126.790845165] [ball_detector_nvidia]: Loading TensorRT engine: /home/ubuntu/robot_ws/src/balance/models/ball_detector_v4.engine
[INFO] [1777504126.794908312] [ball_detector_nvidia]: TensorRT engine loaded — running warmup inferences
Loading /home/ubuntu/robot_ws/src/balance/models/ball_detector_v4.engine for TensorRT inference...
[04/29/2026-23:08:46] [TRT] [I] Loaded engine size: 8 MiB
[04/29/2026-23:08:47] [TRT] [I] [MemUsageChange] TensorRT-managed allocation in engine deserialization: CPU +0, GPU +5, now: CPU 0, GPU 5 (MiB)
[04/29/2026-23:08:47] [TRT] [I] [MemUsageChange] TensorRT-managed allocation in IExecutionContext creation: CPU +0, GPU +9, now: CPU 0, GPU 14 (MiB)
[INFO] [1777504127.372610392] [ball_detector_nvidia]: TRT warmup 1/3: 576.2ms
[INFO] [1777504127.384929564] [ball_detector_nvidia]: TRT warmup 2/3: 10.9ms
[INFO] [1777504127.396973207] [ball_detector_nvidia]: TRT warmup 3/3: 10.8ms
[19443010E156077E00] [1.2.2] [1.067] [ColorCamera(0)] [warning] Unsupported resolution set for detected camera IMX378/214, needs 1080_P / 4_K / 12_MP. Defaulting to 1080_P
[INFO] [1777504129.988719848] [ball_detector_nvidia]: OAK-D connected: OAK-D-LITE  USB HIGH  (camera-only mode, MJPEG q=85)
[INFO] [1777504129.990624073] [ball_detector_nvidia]: ball_detector_nvidia ready  engine=ball_detector_v4.engine  input=640px  conf=0.3  iou=0.45  rgb_fps=35  mjpeg_q=85  debug_fps=5.0
[INFO] [1777504130.121832326] [ball_detector_nvidia]: Cup  bbox: 223x233px  conf=0.897
[INFO] [1777504130.123852747] [ball_detector_nvidia]: Ball bbox: 34x53px  conf=0.532
[INFO] [1777504131.135371740] [ball_detector_nvidia]: Cup  bbox: 223x229px  conf=0.903
[INFO] [1777504131.136420192] [ball_detector_nvidia]: Ball bbox: 32x50px  conf=0.736

```

### Step 2: Start rviz2 on the Nvidia Nano
Even if the initial camera works well upon boot (high confidence recognition) its no guarantee that the one of the tipping poses will cause the ball bearing to fall out of the camera view. Rviz2 and the debug picture topic sent by the ball detector node are useful to tune camera placement and optimal lighting. Rviz2 really can't be run on the RPI5 due to capacity limitations.

```
ubuntu@bueche-nvidia-nano:~/robot_ws/src$ ros2 run rviz2 rviz2

```

### Step 3: Start ball marker node on Nvidia Nano

```
ubuntu@bueche-nvidia-nano:~/robot_ws$ ros2 run balance ball_marker_node
[INFO] [1783545409.262960482] [ball_marker_node]: ball_marker_node ready
```

### Step 4: Launch the robot
Very similar to the non-balance one, but there is a special launch file (`koch_v11_real_robot_for_balance.launch.py`) to capture the URDF specific to this balance sub-project: this URDF adds a cup and ball.
```
ubuntu@bueche-rpi5:~/robot_ws$ ros2 launch writing_robot_description koch_v11_real_robot_for_balance.launch.py
[INFO] [launch]: All log files can be found below /home/ubuntu/.ros/log/2026-07-08-21-38-31-032445-bueche-rpi5-608
[INFO] [launch]: Default logging verbosity is set to INFO
[INFO] [servo_config_node-1]: process started with pid [611]
[INFO] [robot_state_publisher-2]: process started with pid [612]
[robot_state_publisher-2] [WARN] [1783546711.317092766] [kdl_parser]: The root link base_link has an inertia specified in the URDF, but KDL does not support a root link with an inertia.  As a workaround, you can add an extra dummy link to your URDF.
[robot_state_publisher-2] [INFO] [1783546711.317259934] [robot_state_publisher]: Robot initialized
[servo_config_node-1] === servo_config_node: configuring Dynamixel servos ===
[servo_config_node-1] Opened /dev/ttyOpenRB
[servo_config_node-1] Baud rate set to 1000000
[servo_config_node-1] 
[servo_config_node-1]   Configuring ID 2  shoulder_lift  [XL430]
[servo_config_node-1]   ok mode=position P=640 I=0 D=9000 FF1=0 FF2=0 vel=0 acc=0 goal_curr=0
[servo_config_node-1] 
[servo_config_node-1]   Configuring ID 3  elbow_flex     [XL330]
[servo_config_node-1]   ok mode=current-pos P=2000 I=0 D=0 FF1=0 FF2=0 vel=200 acc=50 goal_curr=600
[servo_config_node-1] 
[servo_config_node-1]   Configuring ID 4  wrist_flex     [XL330]
[servo_config_node-1]   ok mode=position P=2000 I=0 D=0 FF1=0 FF2=0 vel=200 acc=50 goal_curr=0
[servo_config_node-1] 
[servo_config_node-1]   Configuring ID 5  wrist_roll     [XL330]
[servo_config_node-1]   ok mode=position P=2000 I=0 D=0 FF1=0 FF2=0 vel=200 acc=50 goal_curr=0
[servo_config_node-1] 
[servo_config_node-1]   Configuring ID 6  pen_holder     [XL330]
[servo_config_node-1]   ok mode=position P=2000 I=0 D=0 FF1=0 FF2=0 vel=200 acc=50 goal_curr=200
[servo_config_node-1] 
[servo_config_node-1] === servo_config_node: done ===
[INFO] [servo_config_node-1]: process has finished cleanly [pid 611]
[INFO] [ros2_control_node-3]: process started with pid [624]
[ros2_control_node-3] [INFO] [1783546
:
:
```

### Step 5: Launch the ball balance node and wrist balance controller
These are also discussed in more detail in the [documentation for the balance node](./ball_balance_node.md) and that for the [wrist balance controller](./wrist_balance_controller.md).

### Step 6: Launch the power monitor and imu node
These take care of the external sensors (INA226 current sensors and IMU sensor).

```
ubuntu@bueche-rpi5:~/robot_ws$ ros2 run writing_robot_control power_monitor_node

[INFO] [1783546835.463551482] [power_monitor_node]: Connected to ESP32 on /dev/ttyIna219 at 115200 baud
[INFO] [1783546837.464657527] [power_monitor_node]: Power monitor node started
```

and 

```
ubuntu@bueche-rpi5:~/robot_ws$ ros2 run writing_robot_control imu_balance_node
[INFO] [1783546819.931613581] [imu_balance_node]: Opening serial port /dev/ttyIMU...
[INFO] [1783546819.932385679] [imu_balance_node]: IMU balance node started — /dev/ttyIMU @ 115200 baud, 50Hz publish rate
[INFO] [1783546819.934893583] [imu_balance_node]: Topics: /imu/raw  /imu/balance_error  /imu/balance_cmd  /imu/is_stable
[INFO] [1783546819.937843046] [imu_balance_node]: Calibrate IMU: ros2 service call /imu/calibrate std_srvs/srv/Trigger "{}"
[INFO] [1783546821.032117054] [imu_balance_node]: stty configured CP210x
[INFO] [1783546821.037916645] [imu_balance_node]: CP210x opened O_RDONLY — RTS not asserted, data will flow
[INFO] [1783546821.138958916] [imu_balance_node]: Serial port open — buffer flushed.
[INFO] [1783546821.170528333] [imu_balance_node]: Raw read test (20 bytes): b'# RAW ax=-1556 ay=-1'
[INFO] [1783547017.366142264] [imu_balance_node]: Arm SETTLED — IMU publishing continues.
[INFO] [1783547102.440154454] [imu_balance_node]: Arm MOVING — IMU publishing continues.
[
```
### Step 7: Launch the pid and current loggers 
These nodes store detailed topic information on the movement of the joints and the electrical behavior of the robot respectively. They log their infomration to a file on the file system so should only be running during the actual test.

```
ubuntu@bueche-rpi5:~/robot_ws$ ros2 run writing_robot_control pid_logger
[INFO] [1783547094.259052777] [pid_logger]: pid_logger started — writing to ./pid_log_20260708_214454.csv
[INFO] [1783547094.260191044] [pid_logger]: Logging at /joint_states rate (100Hz) — ball/IMU held at their native rates
[INFO] [1783547102.442729822] [pid_logger]: Pose started: pose 1 - initial (#1)

```
and

```
ubuntu@bueche-rpi5:~/robot_ws$ ros2 run writing_robot_control power_logger
[INFO] [1783546872.491511213] [power_logger_enhanced]: Logging to: power_log_20260708_214112.csv
[INFO] [1783546872.492295236] [power_logger_enhanced]: Tracking: INA226 power (primary) + Servo currents
[INFO] [1783547010.356605090] [power_logger_enhanced]: → Pose started: pose 1 - initial
[INFO] [1783547102.439814915] [power_logger_enhanced]: → Pose started: pose 1 - initial
[INFO] [1783547116.922453863] [power_logger_enhanced]: ← Pose ended: pose 1 - initial
[INFO] [1783547116.923098256] [power_logger_enhanced]:    Peak servo currents (mA):
[INFO] [1783547116.925730365] [power_logger_enhanced]:      elbow_flex  :  339.0
[INFO] [1783547116.927332245] [power_logger_enhanced]:      wrist_flex  :   71.0
[INFO] [1783547116.928105527] [power_logger_enhanced]:      wrist_roll  :   18.0
[INFO] [1783547116.929350294] [power_logger_enhanced]:      pen_holder  :   16.0
:
:
```
### Step 7: turn on the system watch dog node
This monitors the latency of topics and across hosts.
```
ubuntu@bueche-rpi5:~/robot_ws$ ros2 run writing_robot_control system_watchdog
[INFO] [1783546947.102875785] [system_watchdog]: System watchdog started — monitoring 8 topics, reporting at 0.2Hz
[INFO] [1783546952.077402223] [system_watchdog]: === System Watchdog ===
  /ball/position: NO DATA
  /ball/cup_detected: NO DATA
  ✅ /imu/balance_error: 50.3Hz  max_gap=21ms  spikes=0  msgs=251
  /imu/balance_cmd: NO DATA
  ✅ /imu/is_stable: 50.3Hz  max_gap=21ms  spikes=0  msgs=251
  /balance_enabled: NO DATA
  ✅ /joint_states: 100.0Hz  max_gap=13ms  spikes=0  msgs=497
  /ball/image: NO DATA
  Pipeline latency: calibrating...
  Overall: ⚠️  ISSUES DETECTED
[INFO] [1783546957.077359467] [system_watchdog]: === System Watchdog ===
  /ball/position: NO DATA
  /ball/cup_detected: NO DATA
  ✅ /imu/balance_error: 50.0Hz  max_gap=21ms  spikes=0  msgs=501
  /imu/balance_cmd: NO DATA
  ✅ /imu/is_stable: 50.0Hz  max_gap=21ms  spikes=0  msgs=501
  /balance_enabled: NO DATA
  ✅ /joint_states: 100.0Hz  max_gap=13ms  spikes=0  msgs=997
  /ball/image: NO DATA
  Pipeline latency: calibrating...
  Overall: ⚠️  ISSUES DETECTED
[INFO] [1783546962.077551730] [system_watchdog]: === System Watchdog ===
```
### Step 8: Turn on the video capture of rviz animation if desired
We use peek on the nvidia orin nano.

### Step 9: Start the pose and balance sequence
We use the pose test utility for this purpose.

```
ubuntu@bueche-rpi5:~/robot_ws$ ros2 run writing_robot_control pose_test --ros-args -p poses_file:=src/writing_robot_description/config/balance_v1.yaml -p validate:=true -p telemetry:=true -p urdf_file:=src/writing_robot_description/urdf/koch_v11_arm_real_for_balance.urdf -p power_monitoring:=true -p delay:=5.0 -p wait_for_stable:=true -p stable_timeout:=20.0
POWER_MONITORING_AVAILABLEF: True
[INFO] [1783547100.375273498] [pose_test_node]: Loading URDF limits...
[INFO] [1783547100.378236201] [pose_test_node]: ✓ Loaded limits for 6 joints
[INFO] [1783547100.379325597] [pose_test_node]: Initializing telemetry...
[INFO] [1783547100.387277553] [pose_test_node]: ✓ Telemetry initialized (dual-topic mode)
[INFO] [1783547100.387969835] [pose_test_node]:   - Subscribing to /joint_states
[INFO] [1783547100.388619580] [pose_test_node]:   - Subscribing to /dxl_state
[INFO] [1783547100.389486993] [pose_test_node]:   - XL430 servos (IDs 1,2): Load only
[INFO] [1783547100.390356979] [pose_test_node]:   - XL330 servos (IDs 3-6): Current + Load
[INFO] [1783547100.392174954] [pose_test_node]: ✓ Telemetry active
[INFO] [1783547100.397957545] [pose_test_node]: ✓ Power monitoring enabled
[INFO] [1783547100.399250090] [pose_test_node]: ============================================================
[INFO] [1783547100.400570635] [pose_test_node]: POSE TEST NODE INITIALIZED
[INFO] [1783547100.401849458] [pose_test_node]: ============================================================
[INFO] [1783547100.402987613] [pose_test_node]: Joints: 6
[INFO] [1783547100.404043064] [pose_test_node]: Validation: True
[INFO] [1783547100.405095089] [pose_test_node]: Telemetry: True
[INFO] [1783547100.406757932] [pose_test_node]: Power Monitoring: Enabled
[INFO] [1783547100.408066329] [pose_test_node]: Movement time: 2.0s
[INFO] [1783547100.409367541] [pose_test_node]: Delay between poses: 5.0s
[INFO] [1783547100.410620438] [pose_test_node]: Wait for stable: YES (timeout: 20.0s)
[INFO] [1783547100.412071632] [pose_test_node]: ============================================================
[INFO] [1783547100.412887155] [pose_test_node]: Waiting for joint trajectory controller...
[INFO] [1783547102.426382814] [pose_test_node]: ✓ Loaded 11 poses from src/writing_robot_description/config/balance_v1.yaml
[INFO] [1783547102.426991077] [pose_test_node]: 
============================================================
[INFO] [1783547102.427521265] [pose_test_node]: POSE SEQUENCE TEST
[INFO] [1783547102.428018361] [pose_test_node]: ============================================================
[INFO] [1783547102.428657680] [pose_test_node]: Total poses: 11
[INFO] [1783547102.429442314] [pose_test_node]: Validation: True
[INFO] [1783547102.430010114] [pose_test_node]: Telemetry: True
[INFO] [1783547102.430557691] [pose_test_node]: ============================================================
[INFO] [1783547102.431205807] [pose_test_node]: 
[1/11] pose 1 - initial
[INFO] [1783547102.432973484] [pose_test_node]:   ✓ shoulder_pan: 1.500 rad (within [0.540, 2.044])
[INFO] [1783547102.434090713] [pose_test_node]:   ✓ shoulder_lift: 2.563 rad (within [2.200, 2.886])
[INFO] [1783547102.434860885] [pose_test_node]:   ✓ elbow_flex: 1.470 rad (within [0.726, 2.250])
[INFO] [1783547102.435565371] [pose_test_node]:   ✓ wrist_flex: 2.700 rad (within [0.297, 2.700])
[INFO] [1783547102.436182411] [pose_test_node]:   ✓ wrist_roll: 1.600 rad (within [-1.448, 1.900])
[INFO] [1783547102.436800100] [pose_test_node]:   ✓ pen_holder: 0.977 rad (within [0.190, 1.600])
[INFO] [1783547102.441800631] [pose_test_node]: → Sent: pose 1 - initial
[INFO] [1783547109.444336614] [pose_test_node]:   ⏳ Waiting for ball to center (timeout: 20.0s)...
[INFO] [1783547116.919794995] [pose_test_node]:   ✓ Cup stable after 7.47s
[INFO] [1783547116.923481795] [pose_test_node]:   📊 Joint States:
[INFO] [1783547116.927325485] [pose_test_node]:   📊 shoulder_pan    [XL430] Pos:  1.497rad Load:  0.50% Volt:11.5V Temp: 36.0°C
[INFO] [1783547116.928125361] [pose_test_node]:   📊 shoulder_lift   [XL430] Pos:  2.494rad Load: 24.70% Volt:11.5V Temp: 39.0°C
[INFO] [1783547116.930858359] [pose_test_node]:   📊 elbow_flex      [XL330] Pos:  1.534rad Curr: -330mA Volt: 4.8V Temp: 29.0°C
[INFO] [1783547116.931532919] [pose_test_node]:   📊 wrist_flex      [XL330] Pos:  2.467rad Curr:   17mA Volt: 4.8V Temp: 23.0°C
[INFO] [1783547116.932140700] [pose_test_node]:   📊 wrist_roll      [XL330] Pos:  1.420rad Curr:    0mA Volt: 4.8V Temp: 23.0°C
[INFO] [1783547116.933323078] [pose_test_node]:   📊 pen_holder      [XL330] Pos:  0.974rad Curr:   15mA Volt: 4.7V Temp: 24.0°C
[INFO] [1783547116.934215695] [pose_test_node]:   ⚡ Power Analysis for "pose 1 - initial":
[INFO] [1783547116.935191719] [pose_test_node]:      Peak 5V current (INA226):  0.409A
[INFO] [1783547116.936076076] [pose_test_node]:      Peak motor sum (XL330s):     0.458A
[INFO] [1783547116.937022934] [pose_test_node]:      5V voltage: 5.42V (min) / 5.97V (max)
[INFO] [1783547116.938087830] [pose_test_node]:      Peak 12V current (INA226): 0.228A
[INFO] [1783547116.939169818] [pose_test_node]:      Peak total power:            4.74W
[INFO] [1783547116.940125324] [pose_test_node]:      Holding current comparison:
[INFO] [1783547116.941109867] [pose_test_node]:        Supply current (INA226):  0.388A
[INFO] [1783547116.941983743] [pose_test_node]:        Motor current sum (XL330s):  0.362A
[INFO] [1783547116.943054249] [pose_test_node]:        ✓ Supply within 50mA of  motor sum
[INFO] [1783547116.943754402] [pose_test_node]: 
[2/11] pose 2 -tilt cup right
[INFO] [1783547116.944361053] [pose_test_node]:   ✓ shoulder_pan: 1.500 rad (within [0.540, 2.044])
[INFO] [1783547116.944949613] [pose_test_node]:   ✓ shoulder_lift: 2.563 rad (within [2.200, 2.886])
[INFO
```

### Step 10: Save data and analyze
After each run we collect and analyze data. 
1. add the output of the `pose_test`, `ball_balance_node`, `wrist_balance_controller`, `ball_detector node`, and `system watch dog node` to a single file (called: `test.results.MMDDYYY.tN.cv3.txt` where N = number of tests in the day MMDDYYY).
2. do the overall analysis. Example: `%python3 balance_analysis.v10.py test.results.070826.t1.cv3.txt  > test.analysis.070826.t1.cv3.txt`
3. do the correction analysis. Example: `% python3 corr_analysis.v3.py test.results.070826.t1.cv3.txt  --max-steps 100 > test.corr.070826.t1.cv3.txt`
4. upload all of the data into the google drive.

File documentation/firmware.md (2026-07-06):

# Firmware setup and configuration

This section provides installation and configuration notes for the firmware for various components: the Dynamixel servos, the openRB 150 controller, the INA219 sensors, and the ESP32 controller (used for the sensors). 

## Sections
- [OpenRB 150](#openrb-150)
- [Dynamixel servos](#dynamixel-servos)
- [ESP32 and Current Sensors](#esp32-and-current-sensors)

## OpenRB 150
- The software environment setup for the OpenRB 150 controller is detailed nicely in the Robotis documentation. See: https://emanual.robotis.com/docs/en/parts/controller/openrb-150/
- One subtlety is that the `usb_to_dynamixel` sketch is packaged with the openRB 150 board manager package, not the `Dynamixel2Arduino` library.
   
<p align="center">
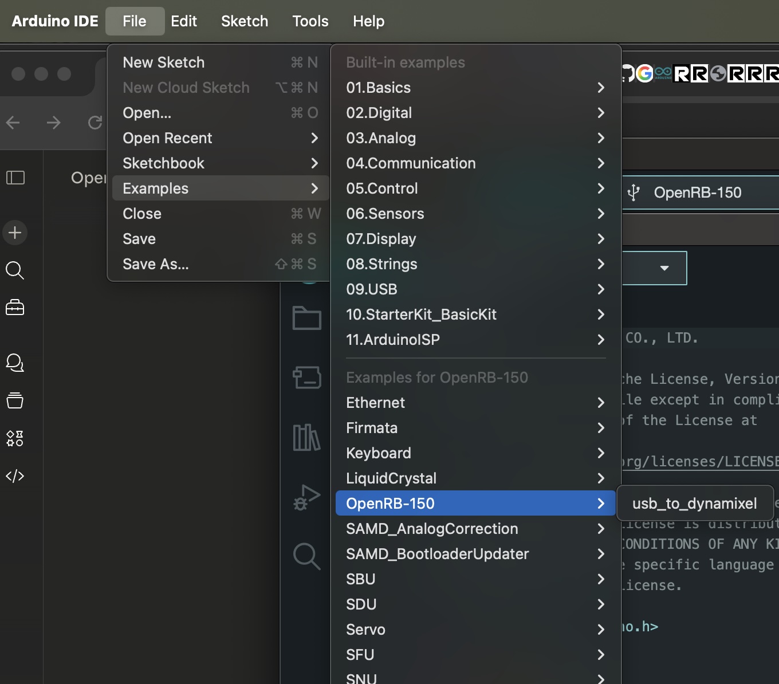
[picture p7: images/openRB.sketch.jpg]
open rb 150 sketch
  
</p>

## Dynamixel servos
Each Dynamixel servo needs to be initialized properly. Again, the documentation for the Dynamixel Wizard provides that information. Aside from updating the firmware, we applied three different configurations:
- The servo ID was set from the factor default of 1 to relect the order defined in the URDF file.
- The communication rate for the servo was changed from the default of 56K to 1M (1000000).
- The max and min position were tuned in an effort to provide safe guards for the moving arm. Although driven by sound motivations, this turned out to be not as useful as desired as we will discuss below.

When all of the servo id's have been properly setup then the Dynamixel wizard will show that they are all found during a scan and each can be examined separately. A successful scan is illustrated below.

<p align="center">
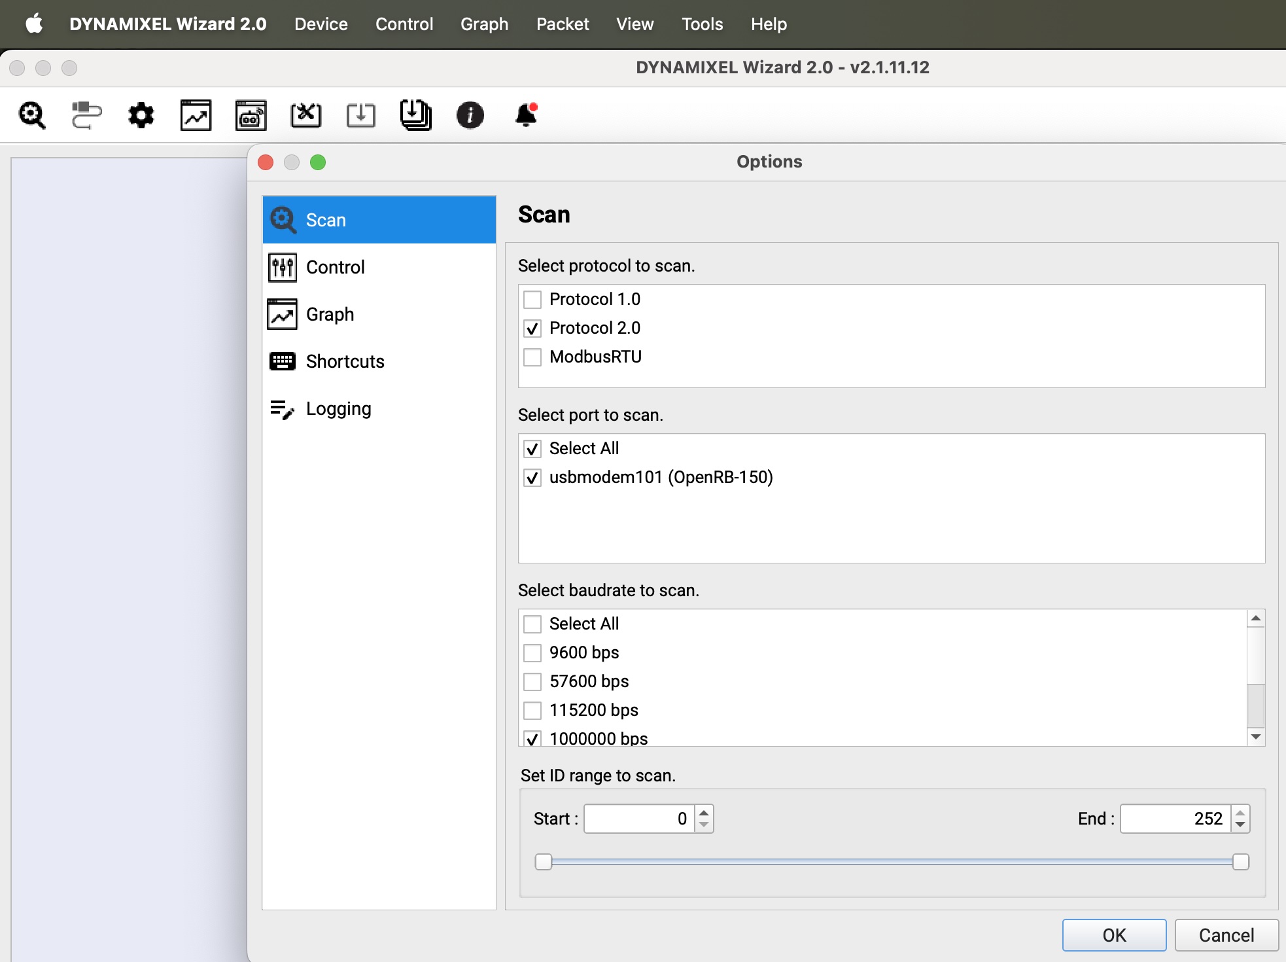
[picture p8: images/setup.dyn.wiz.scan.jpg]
scan
  
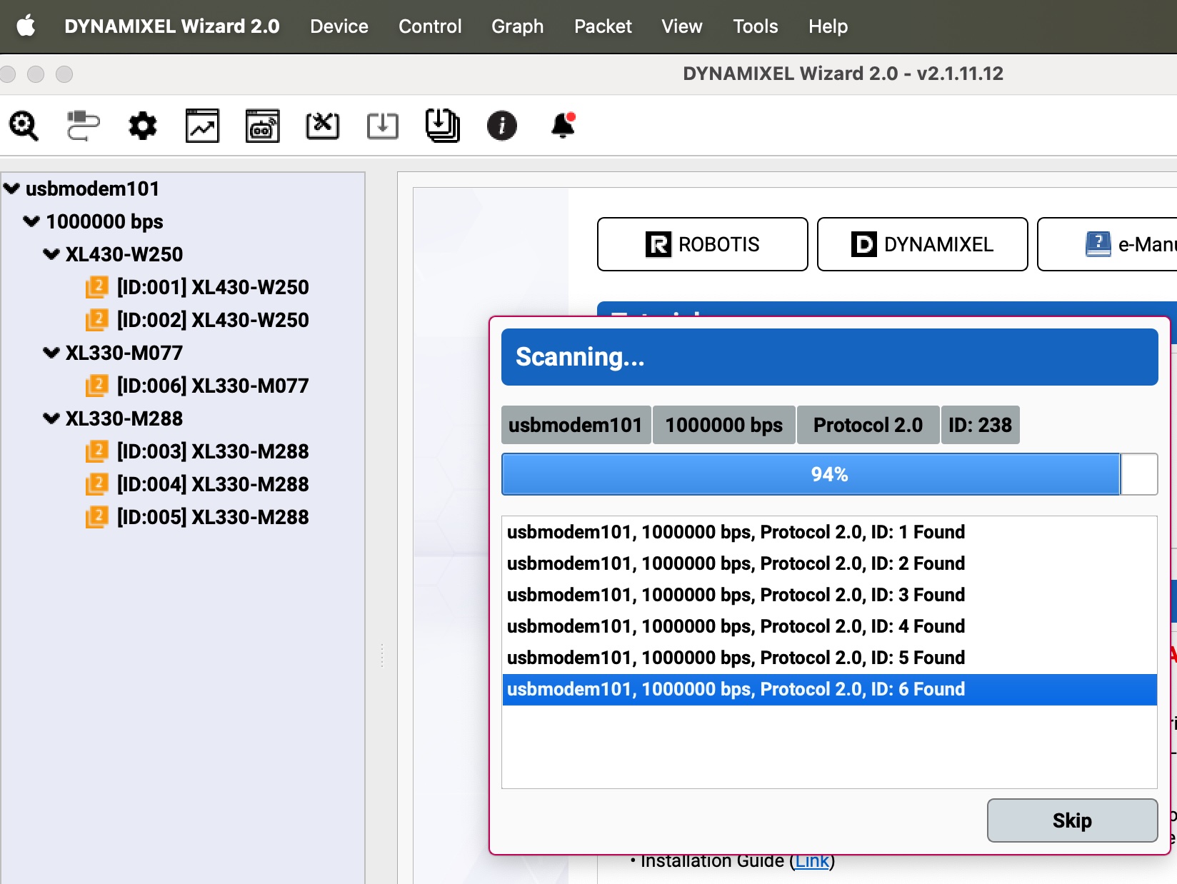
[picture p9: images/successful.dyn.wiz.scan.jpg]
successful scan
  
</p>

Why bother trying to restrict the motion? The motivation was to attempt to prevent the servo from moving in such a way that the arm could be damaged when no collision detection was being enforced. That is, the degrees of freedom of the robot could lead to situations in which the arm was positioned in a way that clearly would not work. An example of this is shown in the display digital twin as the hand is positioned to be below the surface. This could be avoided by restricting the rotation of the `shoulder_lift` joint (which joins the `upper_arm_link` and the `shoulder_link`). 

<p align="center">
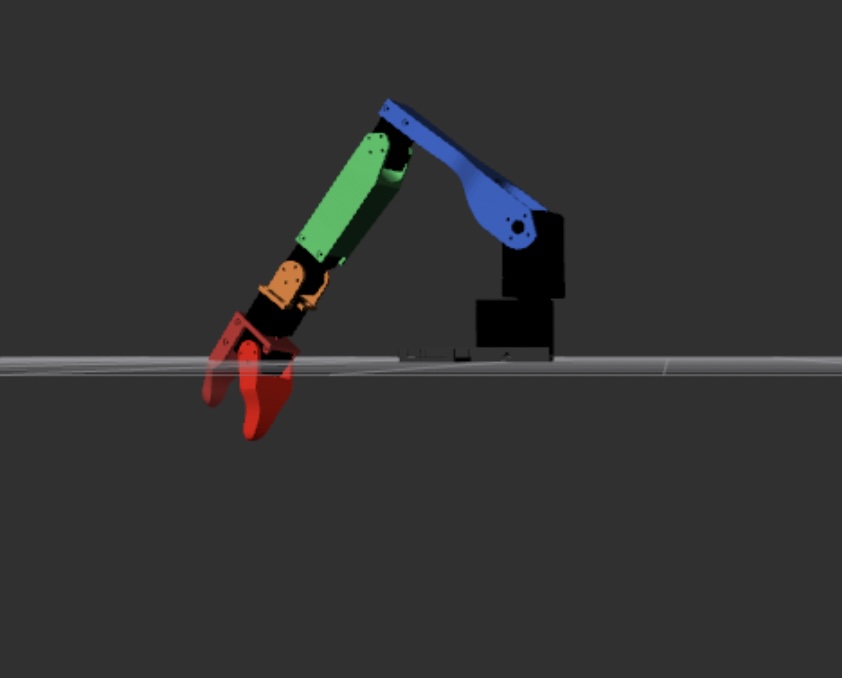
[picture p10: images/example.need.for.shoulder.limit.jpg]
range of motion for servo 2 motivation
  
</p>

This restriction can be enforced using the Max Position Limit and Min Position Limit in the servo as shown below.

<p align="center">
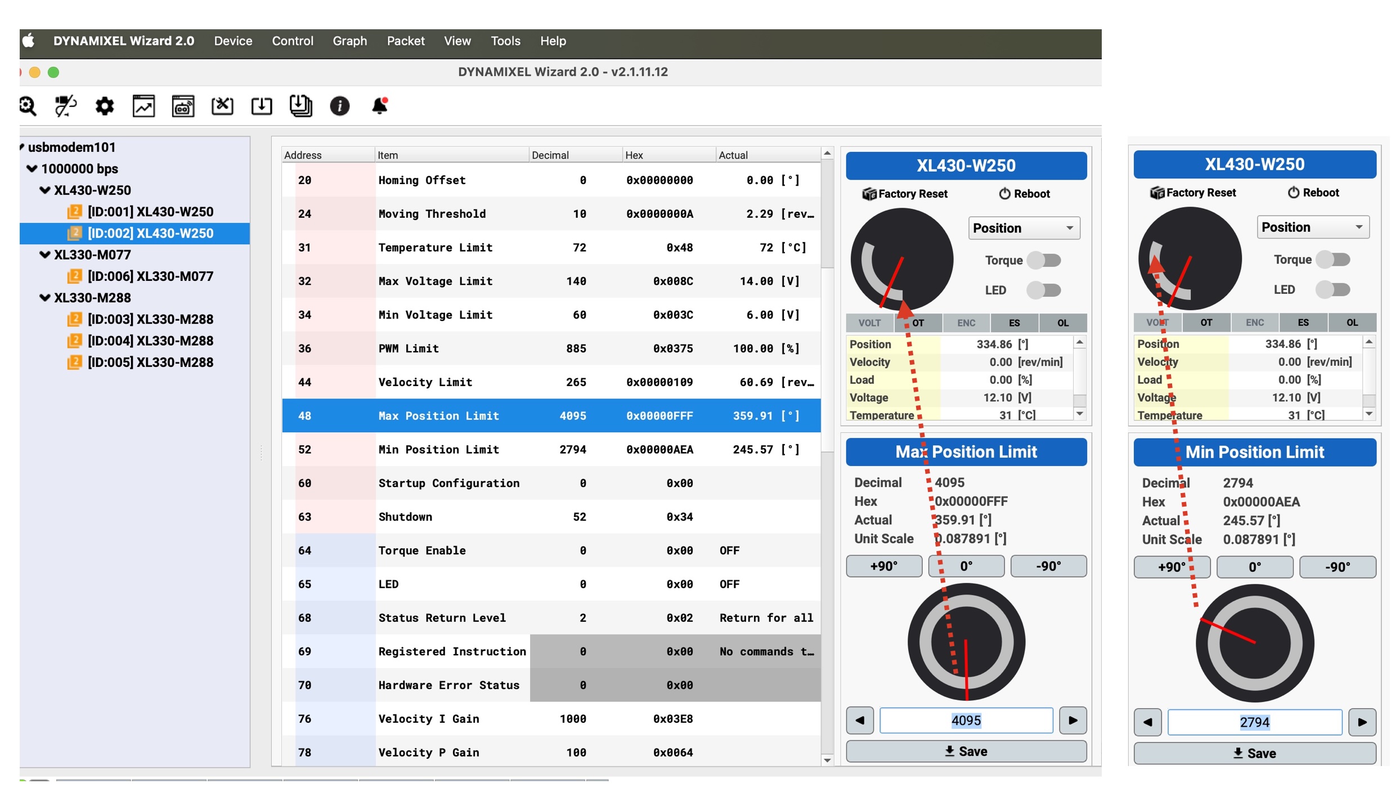
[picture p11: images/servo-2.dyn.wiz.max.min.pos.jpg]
range of motion for servo 2
  
</p>

But was this helpful? In the end, we judge this sort of safeguard as only partially helpful for the following reasons:
1. *Safe movement depends partially on the position of the other joints/links, so this mechanism is perhaps too primitive and limited*. For example, if the `wrist_flex` joint points up then the `shoulder_lift` can rotate more. This is illustrated below. I'm expecting to get more sophistication from [MoveIt2](https://moveit.picknik.ai/main/index.html) ... stay tuned.

<p align="center">
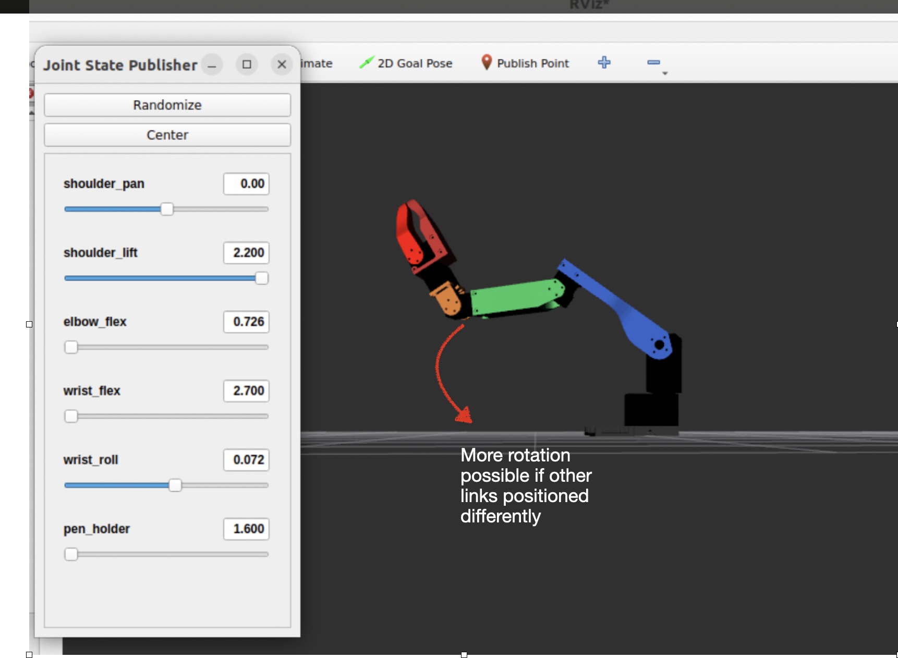
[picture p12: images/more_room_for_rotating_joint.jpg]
lower possible range of motion for servo 2
  
</p>

2. *The behavior of the robot when hitting these underlying limits in ros2 was unpredictable.* It was far more deterministric to use the limits defined in the URDF file as shown below. 

```
<!-- Joint 2: shoulder_lift -->
  <joint name="shoulder_lift">
    <command_interface name="position">
      <param name="min">2.8857</param>  <!-- highest physical position -->
      <param name="max">2.2000</param>   <!-- lowest physical position -->
    </command_interface>
    <state_interface name="position"/>
    <state_interface name="velocity"/>
    <state_interface name="effort"/>
  </joint>
```

The main difficulty in using these limits were that they had to be manually determined by manually positioning each arm and querying their ROS2 radian-based positions and then working out whether max was the lowest position or the highest position.  

**Note** I believe it is possible that the reader might attach the servos such that this order is reversed. This means that using the URDF I've provided might require additional testing to ensure its calibrated to the choices you made.  That is, note in the previous diagram that Max and Min boundaries seem a little unintuitive as the Max seems to restrict physically lower movement and the Min restricts the upper movement. This happens because clock-wise (CW) movement of the frontside wheel is considered movement in the negative direction and the counter clock wise movement (CCW) is considered positive (by default). So depending on how you oriented the servo and when attaching the brackets, the movement of the arm being "up" will be considered positive or negative. This is illustrated below.

<p align="center">
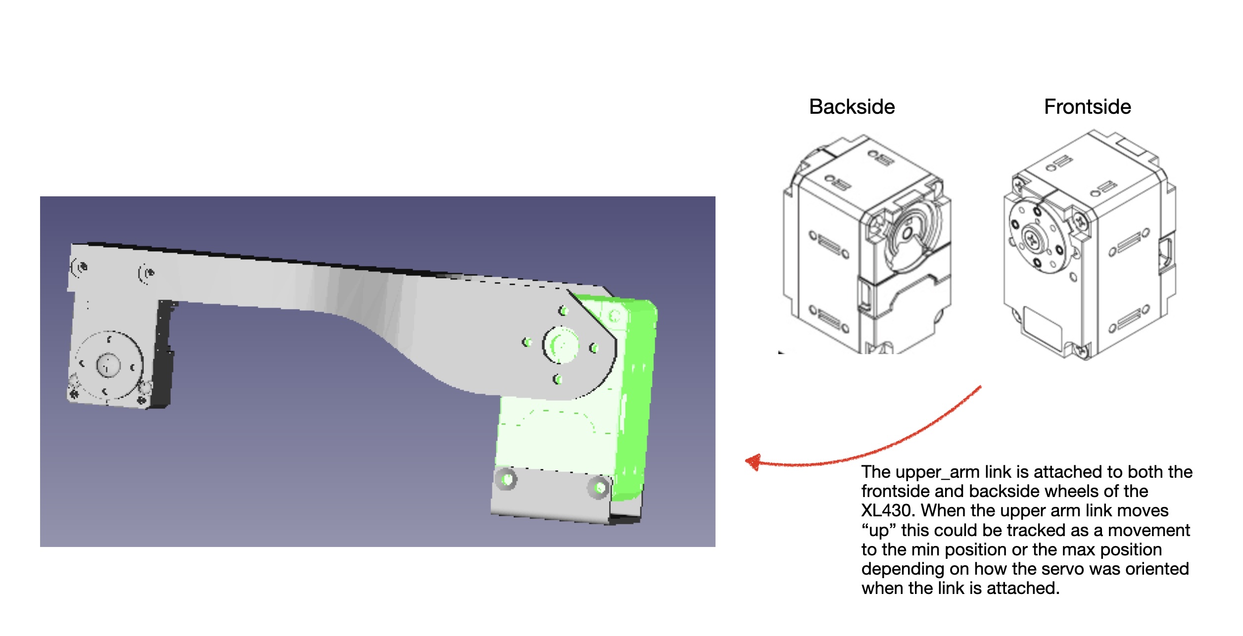
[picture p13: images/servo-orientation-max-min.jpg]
mounting orientation
  
</p>

Finally, note that the Dynamixel Wizard allows the user to query telemetry values like the input current, temperature, voltage, and load, but only for one servo at a time. See the example below. So part of our motivation for enhancing the pull of these in the ros2 environment was to collect that data under regular use and when multiple servos were in action.

<p align="center">
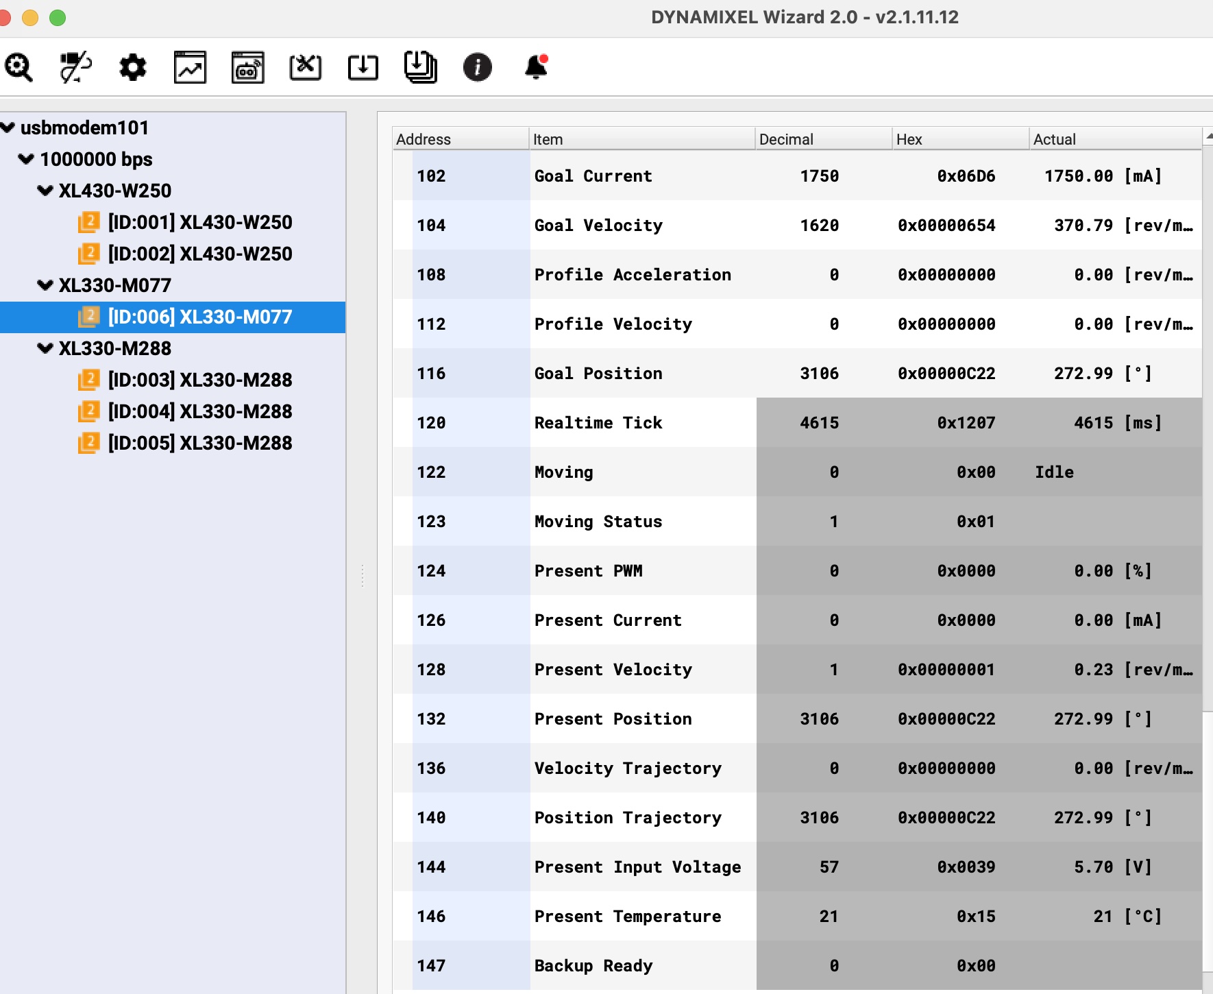
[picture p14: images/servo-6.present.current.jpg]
more telemetry
  
</p>

And related to our discussion above, both the load or the current values reported by the Dynamixel servo can be negative or positive. In this context "negative current" just means that the input current is used to rotate the wheel in the CW or negative direction. It is disconnected from the concept of an alternating current direction.  This is similarly applied to the load metric of the XL430s. So, later in the [documenation on the `pose_test.py` utility](https://github.com/bueche/ros2_robot_arm/blob/main/documentation/pose_test.md) the output which shows negative current or negative load is just showing which direction the wheel was turning. This is why we consider the total current draw from the servo's to be be the sum of the absolute value of each current draw.

```
INFO] [1770595614.927827338] [pose_test_node]: → Sent: pose 1 - poised to work
[INFO] [1770595618.934589703] [pose_test_node]:   📊 Joint States:
[INFO] [1770595618.935407226] [pose_test_node]:   📊 shoulder_pan    [XL430] Pos:  1.557rad Load:  0.00% Volt:12.1V Temp: 32.0°C
[INFO] [1770595618.936180933] [pose_test_node]:   📊 shoulder_lift   [XL430] Pos:  2.839rad Load: 14.00% Volt:12.1V Temp: 34.0°C
[INFO] [1770595618.937008160] [pose_test_node]:   📊 elbow_flex      [XL330] Pos:  2.303rad Curr: -109mA Volt: 5.5V Temp: 21.0°C
[INFO] [1770595618.937838905] [pose_test_node]:   📊 wrist_flex      [XL330] Pos:  2.276rad Curr:   13mA Volt: 5.4V Temp: 21.0°C
[INFO] [1770595618.938645446] [pose_test_node]:   📊 wrist_roll      [XL330] Pos:  1.186rad Curr:  -12mA Volt: 5.5V Temp: 22.0°C
[INFO] [1770595618.939474062] [pose_test_node]:   📊 pen_holder      [XL330] Pos:  1.621rad Curr:  -21mA Volt: 5.4V Temp: 22.0°C
[INFO] [1770595618.940354344] [pose_test_node]:   ⚡ Power Analysis for "pose 1 - poised to work":
[INFO] [1770595618.941070959] [pose_test_node]:      Peak 5V current (INA219):    0.199A
[INFO] [1770595618.941883204] [pose_test_node]:      Peak motor sum (XL330s):     0.162A
[INFO] [1770595618.942663431] [pose_test_node]:      5V voltage: 5.66V (min) / 5.78V (max)
```

## ESP32 and Current Sensors
Now while the openRB 150 communicates via its dynamixel protocol with the servos, when working with the current sensors and the ESP32 a different communication bus and protocol are used ([I2C](https://en.wikipedia.org/wiki/I2C)). The wiring of this is shown in the hardware section of this project. We are using multiple INA219 sensors and two different I2C busses: one for the INA219 sensors and one for the INA226 sensor. 

Since there are multiple devices on the same bus, one must ensure that they all have different addresses (similar to the servo id on the dynamixel servos ... they must all have different ids). I found that there were at least two approaches to achieve this when buying set of sensors:
1. All could have the default address (typically 0x40) and its necessary to solder some pads on the sensor to change the address, or
2. They might be pre-programed to have different addresses. If so, then its necessary to probe the bus to see which address the sensor responds to.
   
The picture below shows where I needed to solder to get one of the INA219 sensors to respond to a different I2C address.

<p align="center">
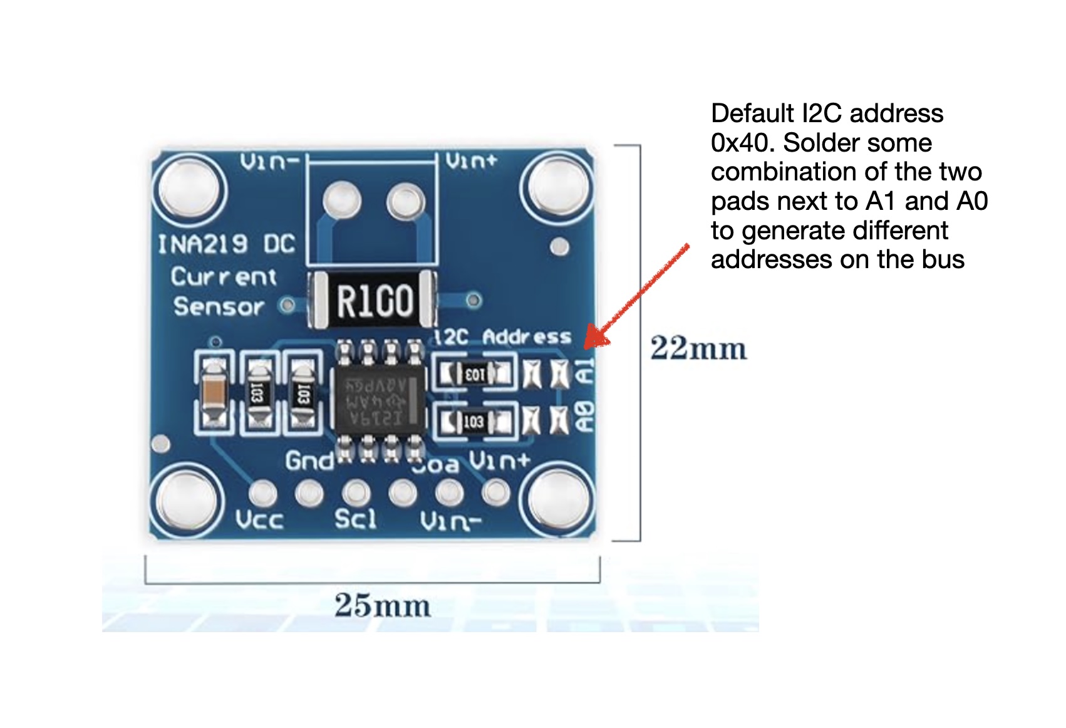
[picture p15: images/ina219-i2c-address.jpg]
i2c addressing on INA219
  
</p>

This information then needs to be reflected into the ESP32 sketch (either [read_ina219_ina226.ino](https://github.com/bueche/ros2_robot_arm/blob/main/power_monitor/sketch/read_ina219_ina226.ino) or [read_ina219.ino](https://github.com/bueche/ros2_robot_arm/blob/main/power_monitor/sketch/read_ina219.ino)) as noted below. Notice the two I2C buses and the initialization of the sensors and their addresses. 

```
// ---------- I2C Bus 0 pins (INA219 sensors) ----------
#define I2C0_SDA 1
#define I2C0_SCL 2

// ---------- I2C Bus 1 pins (INA226 sensor) ----------
// ESP32-S3 - INA226 is connected to these pins
// Exact brand: ESP32-S3 N16R8 (Lonely Binary) found on Amazon
#define I2C1_SDA 21
#define I2C1_SCL 47

// Create second I2C bus object
TwoWire I2C_Bus1 = TwoWire(1);

// ---------- INA219 sensors on Bus 0 ----------
// 12V rail on address 0x40 (default)
Adafruit_INA219 ina219_12v(0x40);
// 5V rail on address 0x41 (second module, address jumper set!)
Adafruit_INA219 ina219_5v(0x41);

// ---------- INA226 sensor on Bus 1 ----------
// Can use address 0x44 or 0x40(found by I2C scanner.. but varies per INA226 sensor)
// The MECCANIXITY INA226 (sold on Amazon) sensors are preset with different addresses
// when purchased as a group of sensors. You can't assume a default.
INA226 ina226_5v(0x44, &I2C_Bus1);

```

The approach is a little different for INA226 sensors in that for certain brands their addresses are pre-programmed to be different when sold in a set. Then it is necessary to probe the bus to attempt to find the addresses that have been set.

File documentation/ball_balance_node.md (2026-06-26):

# Ball Balance Node
The `ball_balance_node` implements the core of the PID logic in this system. It consumes topic data about the ball position, IMU data or servo position error information in order to recalculate the three terms in the PID and combine them for an adjustment servo radian position for both the `wrist_flex` and `wrist_roll` joints.

## Table of contents
- [Parameters]()
- [Example invocation]()
- [FAQ](#faq)
 
## Parameters 
# ball_balance_node Parameters

| parameter name | default | description |
|---|---|---|
| `kp_flex` | 0.3 | Proportional gain on the camera ball-position error (y-axis / forward-back) driving the wrist_flex command. |
| `kp_roll` | 0.3 | Proportional gain on the camera ball-position error (x-axis / left-right) driving the wrist_roll command. |
| `kd_flex` | 0.02 | Derivative gain for the flex axis. Multiplies the angular velocity signal selected by `d_term_source` and subtracts it from the command, damping motion in the direction the cup is already moving. Conservative default — tune up carefully. |
| `kd_roll` | 0.02 | Derivative gain for the roll axis. Same damping role as `kd_flex` but for the roll/left-right axis. |
| `d_term_source` | `'joints'` | Selects where the D-term's angular velocity comes from. `'imu'` reads `/imu/raw` gyroscope data (50Hz MPU-6050) but quantizes at 0.000133 rad/s/LSB, which effectively freezes the signal at the slow angular velocities typical of 1Hz corrections. `'joints'` reads `/balance/wrist_velocity`, a finite-difference of joint_states published by wrist_balance_controller (~100Hz), giving finer resolution (~0.0015 rad/s) and directly measuring servo motion rather than cup vibration. |
| `antiwindup_decay` | 0.2 | Decay factor applied to the accumulated I-term when the ball's position error changes sign on an axis (i.e. the ball crosses center). `0.0` fully resets the integral on a sign change; `1.0` disables this decay entirely. Applied independently per axis — flex decays when `error_y` changes sign, roll decays when `error_x` changes sign. Prevents the integral term from continuing to push in a now-wrong direction after overshoot. |
| `ki_flex` | 0.01 | Integral gain, flex axis. Multiplies the accumulated integral term selected by `ki_mode`. |
| `ki_roll` | 0.01 | Integral gain, roll axis. Same role as `ki_flex` for roll. |
| `max_cmd` | 0.3 | Maximum magnitude (rad/s) for the final flex or roll command after PID summation. Commands are clamped symmetrically to `±max_cmd`. |
| `deadband` | 0.05 | Ball position error magnitude (in normalised 0–1 units) below which no correction is issued, preventing the controller from chasing detection noise when the ball is already very close to center. |
| `stable_thresh` | 0.15 | Ball position magnitude threshold below which the ball is considered "stable" for the purposes of `/imu/is_stable` and the centered-hold timer. |
| `publish_hz` | 15.0 | Target rate of the main control loop. Limited in practice by camera throughput (~1.4Hz when ONNX inference runs on CPU rather than the OAK-D's onboard MyriadX). |
| `settle_delay` | 0.5 | Seconds to wait after the arm transitions to `SETTLED` before PID correction begins, giving the arm and cup time to stop vibrating from the pose move itself. |
| `camera_timeout` | 2.0 | Seconds since the last camera frame before the ball position is considered stale and excluded from control. |
| `imu_timeout` | 0.5 | Seconds since the last IMU or joint-velocity reading before that D-term source is considered stale and zeroed. Applies to whichever source `d_term_source` selects. |
| `ball_lost_timeout` | 1.0 | Seconds the ball can go undetected before the controller suspends normal PID correction and begins the jiggle recovery behavior. |
| `jiggle_amplitude` | 0.02 | Command amplitude per axis (rad/s) used during the jiggle recovery pattern when the ball has been lost. |
| `jiggle_start_delay` | 2.0 | Seconds the ball must remain lost before the jiggle pattern starts (separate from and longer than `ball_lost_timeout`, giving a window where the controller is simply paused before trying to recover). |
| `jiggle_hz` | 1.0 | Rate at which the jiggle pattern advances through its 4 phases. Should match the normal correction rate. The pattern is a 4-phase circular sweep — (+flex, 0), (0, +roll), (−flex, 0), (0, −roll) — so a clamped axis near a joint limit simply doesn't move that phase while the other axis still rocks the cup, without needing to duplicate URDF limits in this node. |
| `attempt_timeout` | 30.0 | Seconds before the current balancing attempt is abandoned if the ball has not centered. *(Note: the module docstring lists this default as 5.0; the `declare_parameter` call in code uses 30.0 — code value is authoritative and the docstring should be corrected.)* |
| `centered_hold_time` | 2.0 | Seconds the ball must remain continuously within `stable_thresh` before `/ball/is_centered` publishes True, which signals pose_test to advance immediately. |
| `near_thresh` | 0.30 | Secondary, looser threshold than `stable_thresh` used only for summary statistics (near-center vs tight-center counts), not for control decisions. |
| `use_achievement` | True | Enables scaling of future commands by the servo achievement ratio — an exponential moving average of (achieved delta / commanded delta) per axis. When a servo persistently under-delivers a commanded movement, subsequent commands on that axis are scaled up to compensate. |
| `achievement_alpha` | 0.3 | Exponential Moving Average (EMA) weight used when updating the achievement ratio after each correction. `0` freezes the ratio at its current value; `1` makes it track the latest single sample instantly. This is a way of smoothing a sequence of values over time so a single noisy sample doesn't yank the tracked value around. The update rule is: `new_average = alpha × new_sample + (1 - alpha) × old_average`|
| `achievement_max_scale` | 3.0 | Maximum multiplier the achievement-ratio scaling can apply to a command, preventing runaway amplification if a servo persistently achieves a very small fraction of what's commanded. |
| `achievement_min_cmd` | 0.003 | Minimum absolute commanded delta required before a correction step is used to update the achievement ratio — avoids corrupting the ratio with near-zero HOLD-step commands where achievement percentage would be noisy or meaningless. |
| `ki_mode` | `'ball'` | Selects what the integral term accumulates. `'ball'` is the classic PID integral of ball position error × dt. `'servo'` accumulates the gap between commanded and achieved servo delta per correction step, growing when the servo underperforms rather than when the ball is off-center. `'combined'` accumulates ball error × (1 − achievement) × dt, growing only when the ball is off AND the servo is underperforming. `'none'` disables the integral entirely (independent of the `ki_flex`/`ki_roll` gain values). |
| `ki_windup_limit` | 0.5 | Clamp applied to the integral term's contribution to the command, limiting how much influence accumulated integral can have regardless of how large the raw integral value grows (separate from the absolute integral clamp derived from `max_cmd / ki_*`). |
| `summary_hz` | 1.0 | Rate at which `PID_SUMMARY` log lines are emitted, summarizing proximity statistics accumulated from every `/ball/position` reading during active PID (sampled at the full camera rate, not just at `publish_hz`). |
| `dry_run` | False | When True, computed PID commands are logged but never published to `/imu/balance_cmd` — used for verifying gain behavior without moving the arm. |
| `use_imu` | True | Enables IMU-based behavior. When `d_term_source='imu'`, this gates whether the IMU reading is used at all (False zeroes the D-term and disables the "wrist_velocity stale" warning logic associated with the joints path). When `d_term_source='joints'`, this primarily affects whether the stale-data warning is logged. |

## Example Invocation

```
ubuntu@bueche-rpi5:~/robot_ws$ ros2 run writing_robot_control ball_balance_node --ros-args   -p kp_flex:=0.15 \
-p kp_roll:=0.15   -p ki_flex:=0.20 -p ki_roll:=0.05   -p kd_flex:=0.05 -p kd_roll:=0.05 -p d_term_source:=joints  \
-p max_cmd:=0.3   -p dry_run:=false -p attempt_timeout:=40.0 -p ki_mode:=servo -p use_imu:=true \
-p  antiwindup_decay:=0.2  -p jiggle_start_delay:=1.0 -p jiggle_amplitude:=0.05

[INFO] [1781131297.451881075] [ball_balance_node]: ball_balance_node started.
[INFO] [1781131297.453153223] [ball_balance_node]: Subscriptions: /ball/position  /imu/balance_error  /imu/raw  /arm_state
[INFO] [1781131297.454413334] [ball_balance_node]: D-term: kd_flex=0.05  kd_roll=0.05  use_imu=True  (angular velocity from /imu/raw, NOT tilt angle)
[INFO] [1781131297.455668816] [ball_balance_node]: Publishes: /imu/balance_cmd  /balance_enabled  /ball/is_centered
[INFO] [1781131355.942875522] [ball_balance_node]: Arm state → SETTLED
[INFO] [1781131356.493504540] [ball_balance_node]: PID active — ball balancing started.
[INFO] [1781131356.497476521] [ball_balance_node]: CMD | ball=(-0.480,-0.554) Pflex=-0.0831 Proll=-0.0720 Dflex=-0.0000 Droll=-0.0000 → flex=-0.0831 roll=-0.0720 d_src=joints flex_rate=+0.0000rad/s roll_rate=+0.0000rad/s ach_flex=1.00 ach_roll=1.00 i_flex=+0.0000 i_roll=+0.0000 ki_mode=servo stable=False hold=--
[INFO] [1781131357.431001336] [ball_balance_node]: PID_SUMMARY | frames=12/12  near(30%)=0(0%)  tight(15%)=0(0%)  min=0.698  mean=0.721  ball=(-0.429,-0.581)
[WARN] [1781131357.493920002] [ball_balance_node]: CAM LAG: 168ms since last ball position
[INFO] [1781131357.499315576] [ball_balance_node]: CMD | ball=(-0.429,-0.581) Pflex=-0.0872 Proll=-0.0644 Dflex=+0.0287 Droll=-0.0000 → flex=-0.0584 roll=-0.0644 d_src=joints flex_rate=-0.5749rad/s roll_rate=+0.0000rad/s ach_flex=1.00 ach_roll=1.00 i_flex=+0.0000 i_roll=+0.0000 ki_mode=servo stable=False hold=--
[INFO] [1781131358.429908705] [ball_balance_node]: PID_SUMMARY | frames=11/12  near(30%)=0(0%)  tight(15%)=0(0%)  min=0.682  mean=0.726  ball=(-0.549,-0.404)
[WARN] [1781131358.494645687] [ball_balance_node]: CAM LAG: 152ms since last ball position
[INFO] [1781131358.562227742] [ball_balance_node]: CMD | ball=(-0.549,-0.404) Pflex=-0.0607 Proll=-0.0824 Dflex=+0.0067 Droll=+0.0134 → flex=-0.0480 roll=-0.0698 d_src=joints flex_rate=-0.1344rad/s roll_rate=-0.2687rad/s ach_flex=1.15 ach_roll=0.94 i_flex=+0.0298 i_roll=-0.0156 ki_mode=servo stable=False hold=--
[INFO] [1781131358.695292483] [ball_balance_node]: ANTI-WINDUP roll: error_x -1→+1 i_roll -0.0156→-0.0031 (decay=0.2)
[INFO] [1781131359.028789909] [ball_balance_node]: ANTI-WINDUP flex: error_y -1→+1 i_flex +0.0298→+0.0060 (decay=0.2)
[INFO] [1781131359.031015538] [ball_balance_node]: ANTI-WINDUP roll: error_x +1→-1 i_roll -0.0031→-0.0006 (decay=0.2)
[INFO] [1781131359.160909464] [ball_balance_node]: ANTI-WINDUP roll: error_x -1→+1 i_roll -0.0006→-0.0001 (decay=0.2)
[INFO] [1781131359.432328612] [ball_balance_node]: PID_SUMMARY | frames=7/13  near(30%)=3(43%)  tight(15%)=2(29%)  min=0.104  mean=0.297  ball=(+0.402,+0.166)
[INFO] [1781131359.629603019] [ball_balance_node]: CMD | ball=(+0.181,+0.210) Pflex=+0.0316 Proll=+0.0272 Dflex=-0.0000 Droll=-0.0076 → flex=+0.0504 roll=+0.0269 d_src=joints flex_rate=+0.0000rad/s roll_rate=+0.1530rad/s ach_flex=1.40 ach_roll=1.02 i_flex=+0.0942 i_roll=+0.1487 ki_mode=servo stable=False hold=--
[INFO] [1781131359.760970260] [ball_balance_node]: ANTI-WINDUP roll: error_x +1→-1 i_roll +0.1487→+0.0297 (decay=0.2)
[INFO] [1781131360.294558445] [ball_balance_node]: ANTI-WINDUP roll: error_x +1→-1 i_roll +0.0297→+0.0059 (decay=0.2)
[INFO] [1781131360.430997371] [ball_balance_node]: PID_SUMMARY | frames=10/12  near(30%)=9(90%)  tight(15%)=6(60%)  min=0.057  mean=0.175  ball=(-0.071,+0.061)
[INFO] [1781131360.627889019] [ball_balance_node]: ANTI-WINDUP flex: error_y +1→-1 i_flex +0.1268→+0.0254 (decay=0.2)
[INFO] [1781131360.630826037] [ball_balance_node]: CMD | ball=(+0.000,-0.066) Pflex=-0.0099 Proll=+0.0000 Dflex=-0.0087 Droll=-0.0000 → flex=-0.0135 roll=-0.0038 d_src=joints flex_rate=+0.1738rad/s roll_rate=+0.0000rad/s ach_flex=1.00 ach_roll=1.31 i_flex=+0.0254 i_roll=-0.0766 ki_mode=servo stable=True hold=0.5s
[INFO] [1781131360.761216463] [ball_balance_node]: ANTI-WINDUP flex: error_y -1→+1 i_flex +0.0254→+0.0051 (decay=0.2)
[INFO] [1781131361.095838352] [ball_balance_node]: ANTI-WINDUP flex: error_y +1→-1 i_flex +0.0051→+0.0010 (decay=0.2)
[INFO] [1781131361.098250333] [ball_balance_node]: ANTI-WINDUP roll: error_x -1→+1 i_roll -0.0766→-0.0153 (decay=0.2)
[INFO] [1781131361.294309537] [ball_balance_node]: ANTI-WINDUP flex: error_y -1→+1 i_flex +0.0010→+0.0002 (decay=0.2)
[INFO] [1781131361.296650815] [ball_balance_node]: ANTI-WINDUP roll: error_x +1→-1 i_roll -0.0153→-0.0031 (decay=0.2)
[INFO] [1781131361.431525481] [ball_balance_node]: PID_SUMMARY | frames=11/12  near(30%)=11(100%)  tight(15%)=11(100%)  min=0.011  mean=0.068  ball=(-0.052,+0.016)
[INFO] [1781131361.695678185] [ball_balance_node]: CMD | ball=(-0.093,+0.000) Pflex=+0.0000 Proll=-0.0139 Dflex=-0.0000 Droll=-0.0000 → flex=+0.0038 roll=-0.0142 d_src=joints flex_rate=+0.0000rad/s roll_rate=+0.0000rad/s ach_flex=0.83 ach_roll=1.20 i_flex=+0.0190 i_roll=-0.0043 ki_mode=servo stable=True hold=0.1s
[INFO] [1781131361.828130277] [ball_balance_node]: ANTI-WINDUP roll: error_x -1→+1 i_roll -0.0043→-0.0009 (decay=0.2)
[INFO] [1781131362.094344518] [ball_balance_node]: ANTI-WINDUP roll: error_x +1→-1 i_roll -0.0009→-0.0002 (decay=0.2)
[INFO] [1781131362.294710073] [ball_balance_node]: ANTI-WINDUP roll: error_x -1→+1 i_roll -0.0002→-0.0000 (decay=0.2)
[INFO] [1781131362.427624925] [ball_balance_node]: PID_SUMMARY | frames=10/12  near(30%)=10(100%)  tight(15%)=10(100%)  min=0.011  mean=0.055  ball=(-0.040,+0.005)
[INFO] [1781131363.161026536] [ball_balance_node]: ANTI-WINDUP roll: error_x +1→-1 i_roll -0.0003→-0.0001 (decay=0.2)
[INFO] [1781131363.164185573] [ball_balance_node]: CMD | ball=(-0.064,+0.000) Pflex=+0.0000 Proll=-0.0097 Dflex=-0.0000 Droll=-0.0000 → flex=+0.0038 roll=-0.0097 d_src=joints flex_rate=+0.0000rad/s roll_rate=+0.0000rad/s ach_flex=0.83 ach_roll=1.13 i_flex=+0.0190 i_roll=-0.0001 ki_mode=servo stable=True hold=0.3s
[INFO] [1781131363.429118888] [ball_balance_node]: PID_SUMMARY | frames=9/12  near(30%)=9(100%)  tight(15%)=9(100%)  min=0.027  mean=0.047  ball=(-0.004,+0.027)
[INFO] [1781131364.426983739] [ball_balance_node]: PID_SUMMARY | frames=12/12  near(30%)=12(100%)  tight(15%)=12(100%)  min=0.005  mean=0.032  ball=(+0.013,+0.027)
[INFO] [1781131364.828807794] [ball_balance_node]: Ball centered — held within stable_thresh=0.15 for 2.0s  magnitude=0.000  ball=(+0.000,+0.000)
[INFO] [1781131364.869191090] [ball_balance_node]: Arm state → MOVING
[INFO] [1781131371.880018957] [ball_balance_node]: Arm state → SETTLED
[INFO] [1781131372.427745253] [ball_balance_node]: PID active — ball balancing started.
[WARN] [1781131372.430929456] [ball_balance_node]: Ball lost for 2.9s (>1.0s) — suspending PID.
[INFO] [1781131372.433763419] [ball_balance_node]: Ball lost: published neutral cmd to cancel stale PID command
[INFO] [1781131372.435634734] [ball_balance_node]: JIGGLE | lost=2.9s flex=+0.000 roll=+0.050 (phase=1/4)
[INFO] [1781131372.436735401] [ball_balance_node]: PID_SUMMARY | no ball data this second
[INFO] [1781131373.429711530] [ball_balance_node]: JIGGLE | lost=3.9s flex=-0.050 roll=+0.000 (phase=2/4)
[INFO] [1781131373.431084919] [ball_balance_node]: PID_SUMMARY | frames=0/12  near(30%)=0(0%)  tight(15%)=0(0%)  min=nan  mean=nan  ball=(+0.748,-0.156)
[WARN] [1781131373.493747030] [ball_balance_node]: Ball lost for 4.0s (>1.0s) — suspending PID.
[INFO] [1781131373.768446030] [ball_balance_node]: CMD | ball=(+0.734,-0.162) Pflex=-0.0244 Proll=+0.1100 Dflex=-0.0000 Droll=-0.0070 → flex=-0.0244 roll=+0.1207 d_src=joints flex_rate=+0.0000rad/s roll_rate=+0.1410rad/s ach_flex=1.00 ach_roll=1.30 i_flex=+0.0000 i_roll=+0.3537 ki_mode=servo stable=False hold=--
[INFO] [1781131374.431483566] [ball_balance_node]: PID_SUMMARY | frames=6/12  near(30%)=0(0%)  tight(15%)=0(0%)  min=0.717  mean=0.749  ball=(+0.675,-0.242)
[INFO] [1781131374.828930714] [ball_balance_node]: CMD | ball=(+0.732,-0.105) Pflex=-0.0157 Proll=+0.1099 Dflex=-0.0000 Droll=-0.0080 → flex=-0.0230 roll=+0.1210 d_src=joints flex_rate=+0.0000rad/s roll_rate=+0.1608rad/s ach_flex=0.70 ach_roll=1.10 i_flex=-0.0364 i_roll=+0.3831 ki_mode=servo stable=False hold=--
[INFO] [1781131375.430116788] [ball_balance_node]: PID_SUMMARY | frames=10/12  near(30%)=0(0%)  tight(15%)=0(0%)  min=0.728  mean=0.745  ball=(+0.720,-0.197)
[INFO] [1781131375.830476973] [ball_balance_node]: CMD | ball=(+0.764,-0.142) Pflex=-0.0214 Proll=+0.1145 Dflex=-0.0000 Droll=-0.0000 → flex=-0.0272 roll=+0.1336 d_src=joints flex_rate=+0.0000rad/s roll_rate=+0.0000rad/s ach_flex=0.84 ach_roll=1.07 i_flex=-0.0293 i_roll=+0.3818 ki_mode=servo stable=False hold=--
[INFO] [1781131376.429830047] [ball_balance_node]: PID_SUMMARY | frames=12/12  near(30%)=0(0%)  tight(15%)=0(0%)  min=0.739  mean=0.758  ball=(+0.759,+0.010)
[INFO] [1781131376.831910898] [ball_balance_node]: CMD | ball=(+0.758,-0.069) Pflex=-0.0103 Proll=+0.1137 Dflex=-0.0000 Droll=-0.0000 → flex=-0.0150 roll=+0.1328 d_src=joints flex_rate=+0.0000rad/s roll_rate=+0.0000rad/s ach_flex=0.93 ach_roll=1.05 i_flex=-0.0237 i_roll=+0.3820 ki_mode=servo stable=False hold=--
[INFO] [1781131377.428500176] [ball_balance_node]: ANTI-WINDUP roll: error_x +1→-1 i_roll +0.3823→+0.0765 (decay=0.2)
[INFO] [1781131377.434225527] [ball_balance_node]: PID_SUMMARY | frames=6/12  near(30%)=0(0%)  tight(15%)=0(0%)  min=0.451  mean=0.699  ball=(-0.422,-0.159)
[INFO] [1781131377.828278694] [ball_balance_node]: ANTI-WINDUP flex: error_y -1→+1 i_flex -0.0271→-0.0054 (decay=0.2)
[INFO] [1781131377.830472342] [ball_balance_node]: ANTI-WINDUP roll: error_x -1→+1 i_roll +0.0765→+0.0153 (decay=0.2)
[INFO] [1781131377.833450323] [ball_balance_node]: CMD | ball=(+0.238,+0.060) Pflex=+0.0090 Proll=+0.0357 Dflex=+0.0077 Droll=-0.0000 → flex=+0.0157 roll=+0.0365 d_src=joints flex_rate=-0.1549rad/s roll_rate=+0.0000rad/s ach_flex=0.88 ach_roll=1.04 i_flex=-0.0054 i_roll=+0.0153 ki_mode=servo stable=False hold=--
[INFO] [1781131378.228289175] [ball_balance_node]: ANTI-WINDUP flex: error_y +1→-1 i_flex -0.0054→-0.0011 (decay=0.2)
[INFO] [1781131378.230039305] [ball_balance_node]: ANTI-WINDUP roll: error_x +1→-1 i_roll +0.0153→+0.0031 (decay=0.2)
[INFO] [1781131378.430345471] [ball_balance_node]: PID_SUMMARY | frames=7/12  near(30%)=1(14%)  tight(15%)=0(0%)  min=0.245  mean=0.539  ball=(-0.604,-0.162)
[INFO] [1781131378.895246286] [ball_balance_node]: CMD | ball=(+0.000,+0.194) Pflex=+0.0292 Proll=+0.0000 Dflex=-0.0000 Droll=-0.0000 → flex=+0.0310 roll=+0.0001 d_src=joints flex_rate=+0.0000rad/s roll_rate=+0.0000rad/s ach_flex=1.14 ach_roll=1.03 i_flex=+0.0093 i_roll=+0.0018 ki_mode=servo stable=False hold=--
[INFO] [1781131379.294790304] [ball_balance_node]: ANTI-WINDUP roll: error_x +1→-1 i_roll +0.0018→+0.0004 (decay=0.2)
[INFO] [1781131379.429498841] [ball_balance_node]: PID_SUMMARY | frames=11/12  near(30%)=8(73%)  tight(15%)=6(55%)  min=0.048  mean=0.214  ball=(-0.008,+0.047)
[INFO] [1781131379.561456063] [ball_balance_node]: ANTI-WINDUP roll: error_x -1→+1 i_roll +0.0017→+0.0003 (decay=0.2)
[INFO] [1781131379.694418545] [ball_balance_node]: ANTI-WINDUP roll: error_x +1→-1 i_roll +0.0003→+0.0001 (decay=0.2)
[INFO] [1781131379.897133285] [ball_balance_node]: CMD | ball=(+0.000,+0.153) Pflex=+0.0229 Proll=+0.0000 Dflex=-0.0000 Droll=-0.0000 → flex=+0.0265 roll=+0.0000 d_src=joints flex_rate=+0.0000rad/s roll_rate=+0.0000rad/s ach_flex=1.18 ach_roll=1.03 i_flex=+0.0181 i_roll=+0.0001 ki_mode=servo stable=False hold=--
[INFO] [1781131380.430617063] [ball_balance_node]: PID_SUMMARY | frames=10/11  near(30%)=10(100%)  tight(15%)=6(60%)  min=0.009  mean=0.104  ball=(-0.065,+0.025)
[INFO] [1781131380.494492785] [ball_balance_node]: ANTI-WINDUP roll: error_x -1→+1 i_roll +0.0056→+0.0011 (decay=0.2)
[INFO] [1781131381.030059636] [ball_balance_node]: CMD | ball=(+0.070,+0.000) Pflex=+0.0000 Proll=+0.0104 Dflex=+0.0061 Droll=-0.0000 → flex=+0.0114 roll=+0.0105 d_src=joints flex_rate=-0.1226rad/s roll_rate=+0.0000rad/s ach_flex=1.21 ach_roll=1.19 i_flex=+0.0263 i_roll=+0.0011 ki_mode=servo stable=True hold=0.7s
[INFO] [1781131381.430852877] [ball_balance_node]: PID_SUMMARY | frames=11/12  near(30%)=11(100%)  tight(15%)=11(100%)  min=0.017  mean=0.051  ball=(+0.066,+0.046)
[INFO] [1781131382.162091099] [ball_balance_node]: CMD | ball=(+0.000,+0.057) Pflex=+0.0085 Proll=+0.0000 Dflex=-0.0000 Droll=-0.0000 → flex=+0.0138 roll=+0.0011 d_src=joints flex_rate=+0.0000rad/s roll_rate=+0.0000rad/s ach_flex=1.21 ach_roll=1.15 i_flex=+0.0263 i_roll=+0.0219 ki_mode=servo stable=True hold=0.9s
[INFO] [1781131382.427663747] [ball_balance_node]: PID_SUMMARY | frames=12/12  near(30%)=12(100%)  tight(15%)=12(100%)  min=0.018  mean=0.058  ball=(+0.045,+0.036)
[INFO] [1781131383.294230728] [ball_balance_node]: Ball centered — held within stable_thresh=0.15 for 2.0s  magnitude=0.000  ball=(+0.000,+0.000)
[INFO] [1781131383.329280820] [ball_balance_node]: Arm state → MOVING
[INFO] [1781131390.331033131] [ball_balance_node]: Arm state → SETTLED
[INFO] [1781131390.893503668] [ball_balance_node]: PID active — ball balancing started.
[INFO] [1781131390.899468556] [ball_balance_node]: CMD | ball=(-0.692,-0.156) Pflex=-0.0234 Proll=-0.1037 Dflex=-0.0000 Droll=-0.0000 → flex=-0.0234 roll=-0.1037 d_src=joints flex_rate=+0.0000rad/s roll_rate=+0.0000rad/s ach_flex=1.00 ach_roll=1.00 i_flex=+0.0000 i_roll=+0.0000 ki_mode=servo stable=False hold=--
[INFO] [1781131391.431009593] [ball_balance_node]: PID_SUMMARY | frames=6/6  near(30%)=0(0%)  tight(15%)=0(0%)  min=0.706  mean=0.708  ball=(-0.690,-0.156)
[INFO] [1781131391.962272371] [ball_balance_node]: CMD | ball=(-0.685,-0.169) Pflex=-0.0254 Proll=-0.1027 Dflex=-0.0000 Droll=-0.0000 → flex=-0.0254 roll=-0.1027 d_src=joints flex_rate=+0.0000rad/s roll_rate=+0.0000rad/s ach_flex=1.00 ach_roll=1.00 i_flex=+0.0000 i_roll=+0.0000 ki_mode=servo stable=False hold=--
[INFO] [1781131392.429618426] [ball_balance_node]: PID_SUMMARY | frames=12/12  near(30%)=0(0%)  tight(15%)=0(0%)  min=0.696  mean=0.706  ball=(-0.680,-0.183)
[INFO] [1781131393.029495648] [ball_balance_node]: CMD | ball=(-0.694,-0.154) Pflex=-0.0231 Proll=-0.1040 Dflex=-0.0000 Droll=-0.0000 → flex=-0.0206 roll=-0.1040 d_src=joints flex_rate=+0.0000rad/s roll_rate=+0.0000rad/s ach_flex=1.15 ach_roll=1.00 i_flex=+0.0122 i_roll=+0.0013 ki_mode=servo stable=False hold=--
[INFO] [1781131393.429765962] [ball_balance_node]: PID_SUMMARY | frames=12/12  near(30%)=0(0%)  tight(15%)=0(0%)  min=0.702  mean=0.707  ball=(-0.697,-0.158)
[INFO] [1781131394.097856814] [ball_balance_node]: CMD | ball=(-0.740,-0.060) Pflex=-0.0091 Proll=-0.1110 Dflex=-0.0000 Droll=-0.0000 → flex=-0.0035 roll=-0.1108 d_src=joints flex_rate=+0.0000rad/s roll_rate=+0.0000rad/s ach_flex=1.32 ach_roll=1.01 i_flex=+0.0276 i_roll=+0.0026 ki_mode=servo stable=False hold=--
[INFO] [1781131394.432352869] [ball_balance_node]: PID_SUMMARY | frames=12/12  near(30%)=0(0%)  tight(15%)=0(0%)  min=0.706  mean=0.729  ball=(-0.715,-0.151)
[INFO] [1781131395.161848646] [ball_balance_node]: CMD | ball=(-0.732,-0.089) Pflex=-0.0133 Proll=-0.1097 Dflex=-0.0000 Droll=-0.0000 → flex=-0.0059 roll=-0.1096 d_src=joints flex_rate=+0.0000rad/s roll_rate=+0.0000rad/s ach_flex=1.40 ach_roll=1.00 i_flex=+0.0371 i_roll=+0.0024 ki_mode=servo stable=False hold=--
[INFO] [1781131395.430312257] [ball_balance_node]: PID_SUMMARY | frames=12/12  near(30%)=0(0%)  tight(15%)=0(0%)  min=0.720  mean=0.732  ball=(-0.716,-0.077)
[INFO] [1781131396.161939109] [ball_balance_node]: CMD | ball=(-0.465,+0.461) Pflex=+0.0692 Proll=-0.0698 Dflex=-0.0000 Droll=-0.0000 → flex=+0.0808 roll=-0.0698 d_src=joints flex_rate=+0.0000rad/s roll_rate=+0.0000rad/s ach_flex=1.58 ach_roll=1.00 i_flex=+0.0582 i_roll=+0.0006 ki_mode=servo stable=False hold=--
[INFO] [1781131396.427987035] [ball_balance_node]: ANTI-WINDUP roll: error_x -1→+1 i_roll +0.0549→+0.0110 (decay=0.2)
[INFO] [1781131396.432159257] [ball_balance_node]: PID_SUMMARY | frames=11/12  near(30%)=0(0%)  tight(15%)=0(0%)  min=0.547  mean=0.696  ball=(+0.365,+0.523)
[INFO] [1781131396.894476923] [ball_balance_node]: ANTI-WINDUP roll: error_x +1→-1 i_roll +0.0110→+0.0022 (decay=0.2)
[INFO] [1781131397.161684664] [ball_balance_node]: ANTI-WINDUP roll: error_x -1→+1 i_roll +0.0022→+0.0004 (decay=0.2)
[INFO] [1781131397.167328460] [ball_balance_node]: CMD | ball=(+0.118,+0.065) Pflex=+0.0097 Proll=+0.0177 Dflex=-0.0000 Droll=-0.0000 → flex=+0.0401 roll=+0.0178 d_src=joints flex_rate=+0.0000rad/s roll_rate=+0.0000rad/s ach_flex=1.16 ach_roll=1.30 i_flex=+0.1520 i_roll=+0.0004 ki_mode=servo stable=True hold=0.0s
[INFO] [1781131397.228251090] [ball_balance_node]: ANTI-WINDUP flex: error_y +1→-1 i_flex +0.1520→+0.0304 (decay=0.2)
[INFO] [1781131397.430787478] [ball_balance_node]: PID_SUMMARY | frames=9/12  near(30%)=2(22%)  tight(15%)=1(11%)  min=0.135  mean=0.403  ball=(+0.378,-0.357)
[INFO] [1781131397.828340812] [ball_balance_node]: ANTI-WINDUP flex: error_y -1→+1 i_flex -0.0800→-0.0160 (decay=0.2)
[INFO] [1781131397.830057219] [ball_balance_node]: ANTI-WINDUP roll: error_x +1→-1 i_roll +0.0833→+0.0167 (decay=0.2)
[INFO] [1781131398.094446552] [ball_balance_node]: ANTI-WINDUP flex: error_y +1→-1 i_flex -0.0160→-0.0032 (decay=0.2)
[INFO] [1781131398.361520163] [ball_balance_node]: ANTI-WINDUP flex: error_y -1→+1 i_flex -0.0032→-0.0006 (decay=0.2)
[INFO] [1781131398.365264885] [ball_balance_node]: CMD | ball=(+0.000,+0.100) Pflex=+0.0150 Proll=+0.0000 Dflex=-0.0000 Droll=-0.0000 → flex=+0.0148 roll=+0.0008 d_src=joints flex_rate=+0.0000rad/s roll_rate=+0.0000rad/s ach_flex=1.21 ach_roll=1.05 i_flex=-0.0006 i_roll=+0.0167 ki_mode=servo stable=True hold=0.4s
[INFO] [1781131398.430312737] [ball_balance_node]: PID_SUMMARY | frames=9/12  near(30%)=9(100%)  tight(15%)=6(67%)  min=0.022  mean=0.128  ball=(-0.065,+0.105)
[INFO] [1781131399.228481496] [ball_balance_node]: ANTI-WINDUP flex: error_y +1→-1 i_flex +0.0071→+0.0014 (decay=0.2)
[INFO] [1781131399.427374959] [ball_balance_node]: PID_SUMMARY | frames=12/12  near(30%)=12(100%)  tight(15%)=12(100%)  min=0.025  mean=0.108  ball=(-0.034,+0.023)
[INFO] [1781131399.494661996] [ball_balance_node]: ANTI-WINDUP flex: error_y -1→+1 i_flex -0.0059→-0.0012 (decay=0.2)
[INFO] [1781131399.499608181] [ball_balance_node]: CMD | ball=(+0.000,+0.092) Pflex=+0.0139 Proll=+0.0000 Dflex=+0.0178 Droll=-0.0000 → flex=+0.0314 roll=+0.0005 d_src=joints flex_rate=-0.3561rad/s roll_rate=+0.0000rad/s ach_flex=0.92 ach_roll=0.72 i_flex=-0.0012 i_roll=+0.0098 ki_mode=servo stable=True hold=1.5s
[INFO] [1781131399.761119570] [ball_balance_node]: ANTI-WINDUP flex: error_y +1→-1 i_flex -0.0012→-0.0002 (decay=0.2)
[INFO] [1781131399.894919255] [ball_balance_node]: ANTI-WINDUP flex: error_y -1→+1 i_flex -0.0002→-0.0000 (decay=0.2)
[INFO] [1781131400.027648292] [ball_balance_node]: Ball centered — held within stable_thresh=0.15 for 2.0s  magnitude=0.112  ball=(-0.070,+0.087)
[INFO] [1781131400.056229255] [ball_balance_node]: Arm state → MOVING
[INFO] [1781131407.061756454] [ball_balance_node]: Arm state → SETTLED
[INFO] [1781131407.627659028] [ball_balance_node]: PID active — ball balancing started.
[INFO] [1781131407.631590546] [ball_balance_node]: CMD | ball=(-0.425,-0.585) Pflex=-0.0877 Proll=-0.0637 Dflex=-0.0000 Droll=-0.0000 → flex=-0.0877 roll=-0.0637 d_src=joints flex_rate=+0.0000rad/s roll_rate=+0.0000rad/s ach_flex=1.00 ach_roll=1.00 i_flex=+0.0000 i_roll=+0.0000 ki_mode=servo stable=False hold=--
[INFO] [1781131408.431846639] [ball_balance_node]: PID_SUMMARY | frames=10/10  near(30%)=0(0%)  tight(15%)=0(0%)  min=0.715  mean=0.719  ball=(-0.426,-0.578)
[INFO] [1781131408.695565472] [ball_balance_node]: CMD | ball=(-0.424,-0.578) Pflex=-0.0867 Proll=-0.0636 Dflex=+0.0080 Droll=+0.0080 → flex=-0.0786 roll=-0.0555 d_src=joints flex_rate=-0.1606rad/s roll_rate=-0.1606rad/s ach_flex=1.00 ach_roll=1.00 i_flex=+0.0000 i_roll=+0.0000 ki_mode=servo stable=False hold=--
[INFO] [1781131409.431317194] [ball_balance_node]: PID_SUMMARY | frames=10/12  near(30%)=0(0%)  tight(15%)=0(0%)  min=0.493  mean=0.698  ball=(-0.442,-0.219)
[INFO] [1781131409.494844656] [ball_balance_node]: ANTI-WINDUP roll: error_x -1→+1 i_roll -0.0102→-0.0020 (decay=0.2)
[INFO] [1781131409.763436953] [ball_balance_node]: CMD | ball=(+0.081,-0.232) Pflex=-0.0348 Proll=+0.0121 Dflex=+0.0066 Droll=+0.0066 → flex=-0.0179 roll=+0.0186 d_src=joints flex_rate=-0.1322rad/s roll_rate=-0.1322rad/s ach_flex=1.30 ach_roll=0.96 i_flex=+0.0516 i_roll=-0.0020 ki_mode=servo stable=False hold=--
[INFO] [1781131409.894332175] [ball_balance_node]: ANTI-WINDUP roll: error_x +1→-1 i_roll -0.0020→-0.0004 (decay=0.2)
[INFO] [1781131410.161258915] [ball_balance_node]: ANTI-WINDUP roll: error_x -1→+1 i_roll -0.0004→-0.0001 (decay=0.2)
[INFO] [1781131410.431017637] [ball_balance_node]: PID_SUMMARY | frames=8/12  near(30%)=4(50%)  tight(15%)=1(12%)  min=0.130  mean=0.430  ball=(+0.704,+0.063)
[INFO] [1781131410.829222156] [ball_balance_node]: CMD | ball=(+0.372,+0.000) Pflex=+0.0000 Proll=+0.0558 Dflex=-0.0000 Droll=-0.0000 → flex=+0.0120 roll=+0.0558 d_src=joints flex_rate=+0.0000rad/s roll_rate=+0.0000rad/s ach_flex=1.29 ach_roll=0.97 i_flex=+0.0602 i_roll=+0.0005 ki_mode=servo stable=False hold=--
[INFO] [1781131411.028518952] [ball_balance_node]: ANTI-WINDUP roll: error_x +1→-1 i_roll +0.0005→+0.0001 (decay=0.2)
[INFO] [1781131411.430304970] [ball_balance_node]: PID_SUMMARY | frames=7/12  near(30%)=0(0%)  tight(15%)=0(0%)  min=0.372  mean=0.557  ball=(-0.593,-0.128)
[INFO] [1781131411.561161026] [ball_balance_node]: ANTI-WINDUP roll: error_x -1→+1 i_roll +0.0003→+0.0001 (decay=0.2)
[INFO] [1781131411.829727137] [ball_balance_node]: CMD | ball=(+0.190,+0.000) Pflex=+0.0000 Proll=+0.0286 Dflex=-0.0000 Droll=+0.0082 → flex=+0.0160 roll=+0.0367 d_src=joints flex_rate=+0.0000rad/s roll_rate=-0.1634rad/s ach_flex=1.06 ach_roll=0.98 i_flex=+0.0801 i_roll=+0.0001 ki_mode=servo stable=False hold=--
[INFO] [1781131411.894460451] [ball_balance_node]: ANTI-WINDUP roll: error_x +1→-1 i_roll +0.0001→+0.0000 (decay=0.2)
[INFO] [1781131412.161529710] [ball_balance_node]: ANTI-WINDUP roll: error_x -1→+1 i_roll +0.0000→+0.0000 (decay=0.2)
[INFO] [1781131412.429906766] [ball_balance_node]: PID_SUMMARY | frames=7/12  near(30%)=3(43%)  tight(15%)=0(0%)  min=0.184  mean=0.357  ball=(+0.449,+0.214)
[INFO] [1781131412.760843229] [ball_balance_node]: ANTI-WINDUP flex: error_y +1→-1 i_flex +0.0898→+0.0180 (decay=0.2)
[INFO] [1781131412.762564636] [ball_balance_node]: ANTI-WINDUP roll: error_x +1→-1 i_roll +0.0013→+0.0003 (decay=0.2)
[INFO] [1781131412.829744266] [ball_balance_node]: CMD | ball=(-0.137,-0.114) Pflex=-0.0170 Proll=-0.0206 Dflex=-0.0000 Droll=-0.0000 → flex=-0.0134 roll=-0.0206 d_src=joints flex_rate=+0.0000rad/s roll_rate=+0.0000rad/s ach_flex=1.34 ach_roll=0.99 i_flex=+0.0180 i_roll=+0.0003 ki_mode=servo stable=False hold=--
[INFO] [1781131412.894855710] [ball_balance_node]: ANTI-WINDUP flex: error_y -1→+1 i_flex +0.0180→+0.0036 (decay=0.2)
[INFO] [1781131412.896794932] [ball_balance_node]: ANTI-WINDUP roll: error_x -1→+1 i_roll +0.0003→+0.0001 (decay=0.2)
[INFO] [1781131413.161129858] [ball_balance_node]: ANTI-WINDUP flex: error_y +1→-1 i_flex +0.0036→+0.0007 (decay=0.2)
[INFO] [1781131413.162846784] [ball_balance_node]: ANTI-WINDUP roll: error_x +1→-1 i_roll +0.0001→+0.0000 (decay=0.2)
[INFO] [1781131413.430580284] [ball_balance_node]: PID_SUMMARY | frames=9/12  near(30%)=7(78%)  tight(15%)=3(33%)  min=0.059  mean=0.187  ball=(-0.054,-0.044)
[INFO] [1781131413.494375358] [ball_balance_node]: ANTI-WINDUP roll: error_x -1→+1 i_roll -0.0992→-0.0198 (decay=0.2)
[INFO] [1781131413.761202784] [ball_balance_node]: ANTI-WINDUP roll: error_x +1→-1 i_roll -0.0198→-0.0040 (decay=0.2)
[INFO] [1781131413.829772487] [ball_balance_node]: CMD | ball=(-0.129,-0.067) Pflex=-0.0101 Proll=-0.0194 Dflex=+0.0072 Droll=-0.0000 → flex=-0.0136 roll=-0.0196 d_src=joints flex_rate=-0.1432rad/s roll_rate=+0.0000rad/s ach_flex=1.14 ach_roll=1.29 i_flex=-0.0534 i_roll=-0.0040 ki_mode=servo stable=True hold=0.0s
[INFO] [1781131413.961160172] [ball_balance_node]: ANTI-WINDUP flex: error_y -1→+1 i_flex -0.0534→-0.0107 (decay=0.2)
[INFO] [1781131414.294402746] [ball_balance_node]: ANTI-WINDUP flex: error_y +1→-1 i_flex -0.0107→-0.0021 (decay=0.2)
[INFO] [1781131414.296361042] [ball_balance_node]: ANTI-WINDUP roll: error_x +1→-1 i_roll -0.0040→-0.0008 (decay=0.2)
[INFO] [1781131414.430159857] [ball_balance_node]: PID_SUMMARY | frames=10/12  near(30%)=10(100%)  tight(15%)=9(90%)  min=0.087  mean=0.117  ball=(-0.011,+0.087)
[INFO] [1781131414.760926487] [ball_balance_node]: ANTI-WINDUP roll: error_x +1→-1 i_roll +0.0035→+0.0007 (decay=0.2)
[INFO] [1781131414.895500653] [ball_balance_node]: CMD | ball=(+0.000,+0.149) Pflex=+0.0223 Proll=+0.0000 Dflex=-0.0000 Droll=-0.0000 → flex=+0.0219 roll=+0.0000 d_src=joints flex_rate=+0.0000rad/s roll_rate=+0.0000rad/s ach_flex=1.14 ach_roll=1.28 i_flex=-0.0021 i_roll=+0.0007 ki_mode=servo stable=True hold=0.7s
[INFO] [1781131415.295206801] [ball_balance_node]: ANTI-WINDUP roll: error_x +1→-1 i_roll +0.0007→+0.0001 (decay=0.2)
[INFO] [1781131415.430750579] [ball_balance_node]: PID_SUMMARY | frames=10/12  near(30%)=10(100%)  tight(15%)=10(100%)  min=0.061  mean=0.119  ball=(-0.037,+0.114)
[INFO] [1781131415.962010875] [ball_balance_node]: CMD | ball=(+0.000,+0.221) Pflex=+0.0331 Proll=+0.0000 Dflex=-0.0078 Droll=-0.0000 → flex=+0.0249 roll=-0.0001 d_src=joints flex_rate=+0.1558rad/s roll_rate=+0.0000rad/s ach_flex=1.14 ach_roll=1.17 i_flex=-0.0021 i_roll=-0.0016 ki_mode=servo stable=False hold=--
[INFO] [1781131416.430118819] [ball_balance_node]: PID_SUMMARY | frames=12/12  near(30%)=12(100%)  tight(15%)=5(42%)  min=0.039  mean=0.151  ball=(+0.033,+0.106)
[INFO] [1781131417.030040263] [ball_balance_node]: CMD | ball=(+0.000,+0.219) Pflex=+0.0329 Proll=+0.0000 Dflex=-0.0000 Droll=-0.0000 → flex=+0.0394 roll=-0.0001 d_src=joints flex_rate=+0.0000rad/s roll_rate=+0.0000rad/s ach_flex=0.90 ach_roll=1.17 i_flex=+0.0326 i_roll=-0.0016 ki_mode=servo stable=False hold=--
[INFO] [1781131417.430995411] [ball_balance_node]: PID_SUMMARY | frames=9/11  near(30%)=9(100%)  tight(15%)=3(33%)  min=0.016  mean=0.160  ball=(+0.133,+0.133)
[WARN] [1781131417.494097837] [ball_balance_node]: CAM LAG: 161ms since last ball position
[INFO] [1781131418.097101633] [ball_balance_node]: CMD | ball=(+0.000,+0.094) Pflex=+0.0141 Proll=+0.0000 Dflex=-0.0000 Droll=-0.0000 → flex=+0.0247 roll=+0.0009 d_src=joints flex_rate=+0.0000rad/s roll_rate=+0.0000rad/s ach_flex=0.70 ach_roll=0.82 i_flex=+0.0530 i_roll=+0.0182 ki_mode=servo stable=True hold=0.1s
[INFO] [1781131418.429634688] [ball_balance_node]: PID_SUMMARY | frames=10/12  near(30%)=10(100%)  tight(15%)=8(80%)  min=0.024  mean=0.098  ball=(+0.027,+0.082)
[INFO] [1781131418.761388206] [ball_balance_node]: ANTI-WINDUP flex: error_y +1→-1 i_flex +0.0681→+0.0136 (decay=0.2)
[INFO] [1781131418.961559854] [ball_balance_node]: ANTI-WINDUP flex: error_y -1→+1 i_flex +0.0136→+0.0027 (decay=0.2)
[INFO] [1781131419.160854854] [ball_balance_node]: ANTI-WINDUP flex: error_y +1→-1 i_flex +0.0027→+0.0005 (decay=0.2)
[INFO] [1781131419.162605373] [ball_balance_node]: ANTI-WINDUP roll: error_x +1→-1 i_roll +0.0182→+0.0036 (decay=0.2)
[INFO] [1781131419.165292188] [ball_balance_node]: CMD | ball=(-0.054,-0.051) Pflex=-0.0076 Proll=-0.0081 Dflex=-0.0000 Droll=-0.0000 → flex=-0.0075 roll=-0.0079 d_src=joints flex_rate=+0.0000rad/s roll_rate=+0.0000rad/s ach_flex=0.59 ach_roll=0.82 i_flex=+0.0005 i_roll=+0.0036 ki_mode=servo stable=True hold=0.5s
[INFO] [1781131419.428405243] [ball_balance_node]: ANTI-WINDUP roll: error_x -1→+1 i_roll -0.0057→-0.0011 (decay=0.2)
[INFO] [1781131419.433087521] [ball_balance_node]: PID_SUMMARY | frames=11/13  near(30%)=11(100%)  tight(15%)=11(100%)  min=0.022  mean=0.079  ball=(+0.084,+0.020)
[INFO] [1781131420.229195946] [ball_balance_node]: CMD | ball=(+0.068,+0.000) Pflex=+0.0000 Proll=+0.0102 Dflex=-0.0000 Droll=-0.0000 → flex=+0.0001 roll=+0.0102 d_src=joints flex_rate=+0.0000rad/s roll_rate=+0.0000rad/s ach_flex=0.59 ach_roll=0.57 i_flex=+0.0005 i_roll=-0.0011 ki_mode=servo stable=True hold=0.1s
[INFO] [1781131420.431118668] [ball_balance_node]: PID_SUMMARY | frames=6/12  near(30%)=6(100%)  tight(15%)=6(100%)  min=0.028  mean=0.072  ball=(+0.080,+0.081)
[INFO] [1781131421.428347946] [ball_balance_node]: PID_SUMMARY | frames=10/12  near(30%)=10(100%)  tight(15%)=9(90%)  min=0.021  mean=0.067  ball=(+0.032,-0.021)
[INFO] [1781131421.629982594] [ball_balance_node]: CMD | ball=(+0.000,+0.055) Pflex=+0.0083 Proll=+0.0000 Dflex=-0.0000 Droll=-0.0000 → flex=+0.0119 roll=+0.0000 d_src=joints flex_rate=+0.0000rad/s roll_rate=+0.0000rad/s ach_flex=0.58 ach_roll=0.75 i_flex=+0.0180 i_roll=+0.0003 ki_mode=servo stable=True hold=0.3s
[INFO] [1781131422.431740260] [ball_balance_node]: PID_SUMMARY | frames=11/12  near(30%)=11(100%)  tight(15%)=11(100%)  min=0.022  mean=0.053  ball=(+0.001,+0.063)
[INFO] [1781131422.761857815] [ball_balance_node]: CMD | ball=(+0.000,+0.070) Pflex=+0.0106 Proll=+0.0000 Dflex=-0.0000 Droll=-0.0000 → flex=+0.0173 roll=+0.0000 d_src=joints flex_rate=+0.0000rad/s roll_rate=+0.0000rad/s ach_flex=0.53 ach_roll=0.75 i_flex=+0.0338 i_roll=+0.0003 ki_mode=servo stable=True hold=1.1s
[INFO] [1781131423.427289648] [ball_balance_node]: PID_SUMMARY | frames=12/12  near(30%)=12(100%)  tight(15%)=12(100%)  min=0.021  mean=0.043  ball=(+0.007,+0.049)
[INFO] [1781131423.760768222] [ball_balance_node]: Ball centered — held within stable_thresh=0.15 for 2.0s  magnitude=0.000  ball=(+0.000,+0.000)
[INFO] [1781131423.798040778] [ball_balance_node]: Arm state → MOVING
[INFO] [1781131430.801853829] [ball_balance_node]: Arm state → SETTLED
[INFO] [1781131431.360199255] [ball_balance_node]: PID active — ball balancing started.
[INFO] [1781131431.364810551] [ball_balance_node]: CMD | ball=(-0.313,+0.663) Pflex=+0.0995 Proll=-0.0470 Dflex=-0.0000 Droll=-0.0000 → flex=+0.0995 roll=-0.0470 d_src=joints flex_rate=+0.0000rad/s roll_rate=+0.0000rad/s ach_flex=1.00 ach_roll=1.00 i_flex=+0.0000 i_roll=+0.0000 ki_mode=servo stable=False hold=--
[INFO] [1781131431.429676625] [ball_balance_node]: PID_SUMMARY | no ball data this second
[WARN] [1781131431.694272365] [ball_balance_node]: CAM LAG: 167ms since last ball position
[INFO] [1781131432.429496235] [ball_balance_node]: CMD | ball=(-0.251,+0.721) Pflex=+0.1082 Proll=-0.0377 Dflex=-0.0000 Droll=-0.0000 → flex=+0.1684 roll=-0.0400 d_src=joints flex_rate=+0.0000rad/s roll_rate=+0.0000rad/s ach_flex=1.15 ach_roll=0.79 i_flex=+0.3011 i_roll=-0.0465 ki_mode=servo stable=False hold=--
[INFO] [1781131432.430700606] [ball_balance_node]: PID_SUMMARY | frames=12/12  near(30%)=0(0%)  tight(15%)=0(0%)  min=0.727  mean=0.751  ball=(-0.251,+0.721)
[INFO] [1781131433.430058901] [ball_balance_node]: CMD | ball=(-0.242,+0.706) Pflex=+0.1059 Proll=-0.0363 Dflex=-0.0000 Droll=-0.0000 → flex=+0.1698 roll=-0.0386 d_src=joints flex_rate=+0.0000rad/s roll_rate=+0.0000rad/s ach_flex=1.04 ach_roll=0.87 i_flex=+0.3198 i_roll=-0.0451 ki_mode=servo stable=False hold=--
[INFO] [1781131433.431457309] [ball_balance_node]: PID_SUMMARY | frames=13/13  near(30%)=0(0%)  tight(15%)=0(0%)  min=0.745  mean=0.755  ball=(-0.242,+0.706)
[INFO] [1781131434.430747401] [ball_balance_node]: PID_SUMMARY | frames=12/12  near(30%)=0(0%)  tight(15%)=0(0%)  min=0.717  mean=0.750  ball=(+0.253,+0.686)
[INFO] [1781131434.495695604] [ball_balance_node]: CMD | ball=(+0.253,+0.686) Pflex=+0.1029 Proll=+0.0379 Dflex=+0.0083 Droll=-0.0083 → flex=+0.1789 roll=+0.0316 d_src=joints flex_rate=-0.1666rad/s roll_rate=+0.1666rad/s ach_flex=0.96 ach_roll=0.88 i_flex=+0.3384 i_roll=+0.0411 ki_mode=servo stable=False hold=--
[INFO] [1781131435.361236845] [ball_balance_node]: ANTI-WINDUP flex: error_y +1→-1 i_flex +0.3384→+0.0677 (decay=0.2)
[INFO] [1781131435.429749419] [ball_balance_node]: PID_SUMMARY | frames=11/11  near(30%)=2(18%)  tight(15%)=1(9%)  min=0.128  mean=0.601  ball=(-0.116,-0.054)
[INFO] [1781131435.561811548] [ball_balance_node]: CMD | ball=(-0.118,-0.290) Pflex=-0.0435 Proll=-0.0177 Dflex=-0.0000 Droll=+0.0083 → flex=-0.0412 roll=-0.0103 d_src=joints flex_rate=+0.0000rad/s roll_rate=-0.1661rad/s ach_flex=1.27 ach_roll=1.22 i_flex=+0.0117 i_roll=-0.0187 ki_mode=servo stable=False hold=--
[INFO] [1781131435.694914659] [ball_balance_node]: ANTI-WINDUP roll: error_x -1→+1 i_roll -0.0187→-0.0037 (decay=0.2)
[INFO] [1781131435.760930030] [ball_balance_node]: ANTI-WINDUP flex: error_y -1→+1 i_flex +0.0117→+0.0023 (decay=0.2)
[INFO] [1781131436.294538289] [ball_balance_node]: ANTI-WINDUP flex: error_y +1→-1 i_flex +0.0023→+0.0005 (decay=0.2)
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

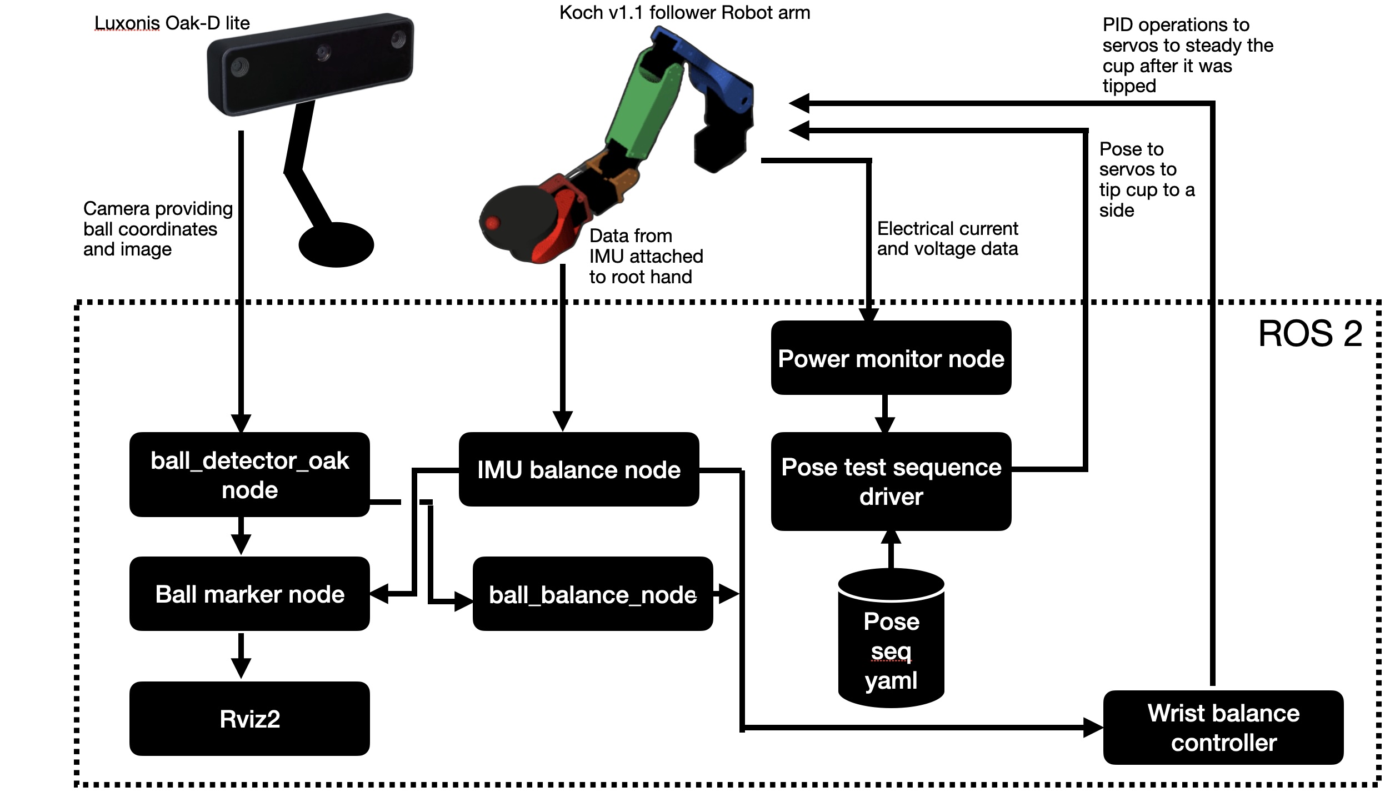
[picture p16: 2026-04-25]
images/balance_high_level_architecture.jpg

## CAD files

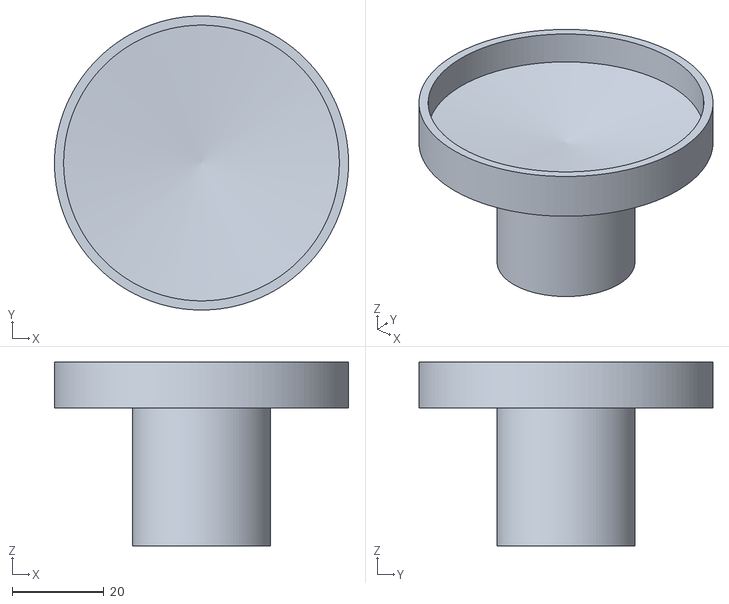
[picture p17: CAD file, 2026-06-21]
writing_robot_description/meshes/cup.v3-Body.stl
64.0 x 64.0 x 40.0

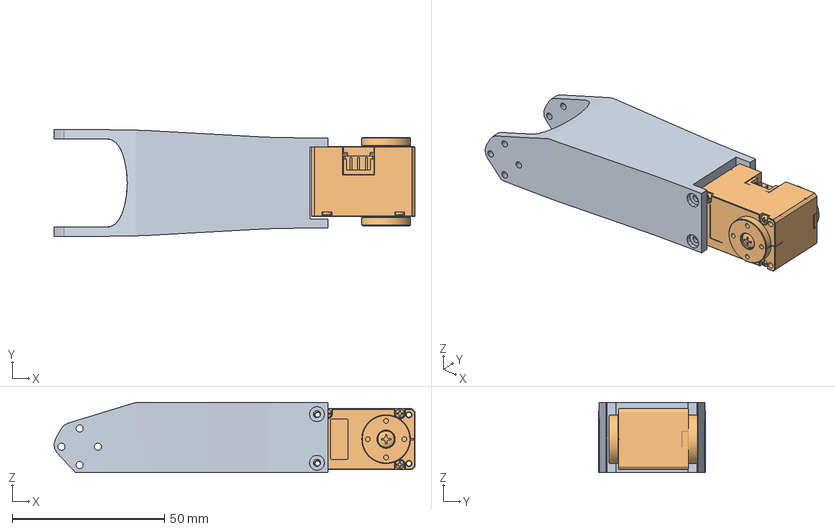
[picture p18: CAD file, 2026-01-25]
writing_robot_description/meshes/scratch_forearm_link_1.FCStd
118.6 x 35.0 x 23.0 mm
Follower_Elbow_To_Wrist_Extension_binary
XL,XC-330

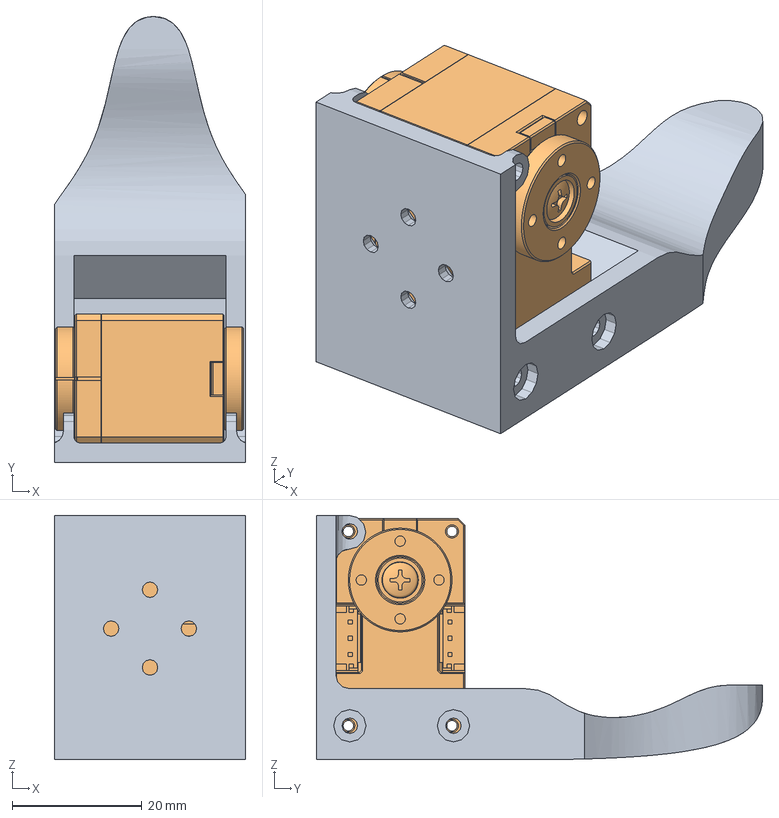
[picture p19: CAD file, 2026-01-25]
writing_robot_description/meshes/scratch.FCStd
29.5 x 68.9 x 37.8 mm
Follower_Gripper_Static_Part_binary
XL,XC-330

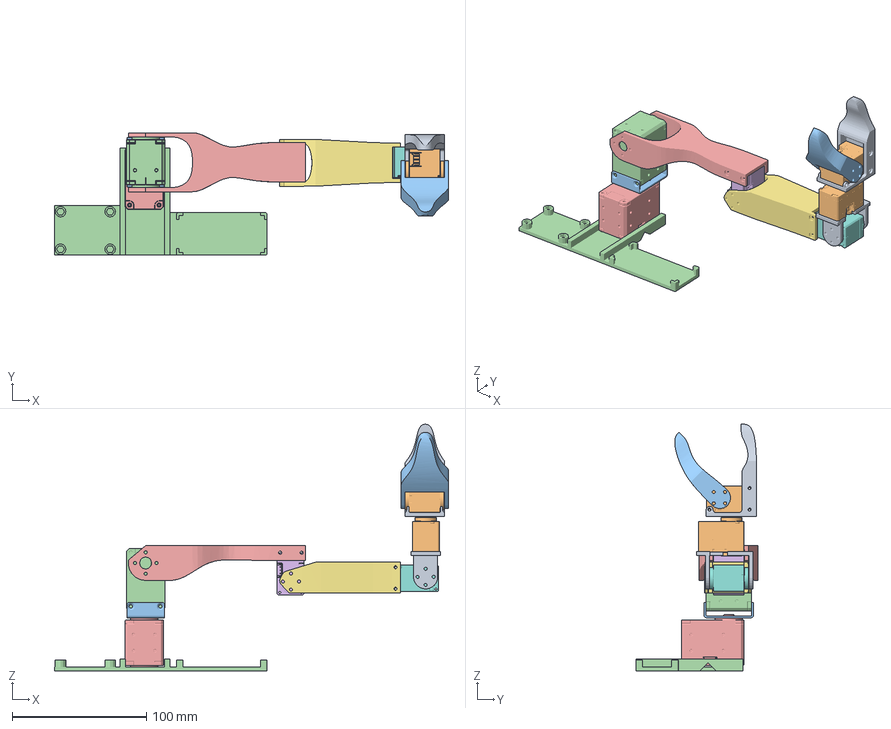
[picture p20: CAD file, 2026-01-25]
writing_robot_description/meshes/robot_arm_v4.FCStd
293.8 x 91.3 x 183.9 mm
Follower_Gripper_Static_Part_binary
XL,XC-332
fr12_s102
XL-430_new
Follower_Shoulder_To_Elbow_binary
XL-330-ID3
Follower_Elbow_To_Wrist_Extension_binary
XL,XC-330
Follower_Elbow_To_Wrist_binary
XL,XC-333
Follower_Gripper_Moving_Part_binary
Follower_Base_binary
XL-430_new001

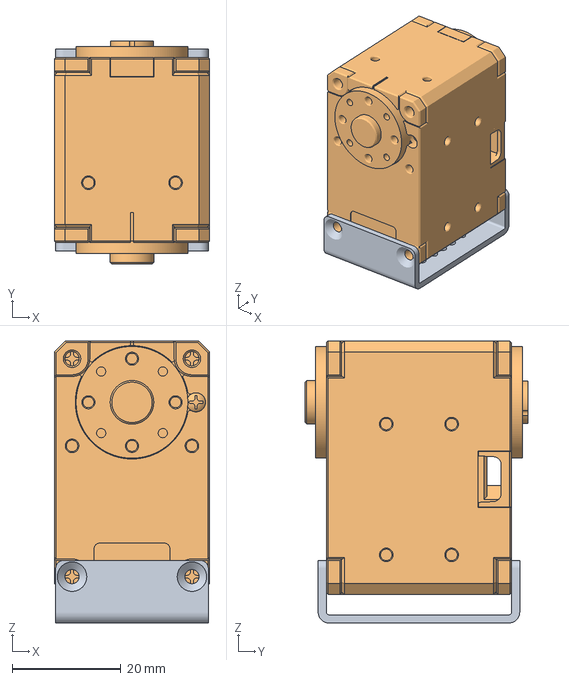
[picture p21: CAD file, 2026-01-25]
writing_robot_description/meshes/scratch_shoulder_link_1.FCStd
28.5 x 40.9 x 51.8 mm
fr12_s102
XL-430_new

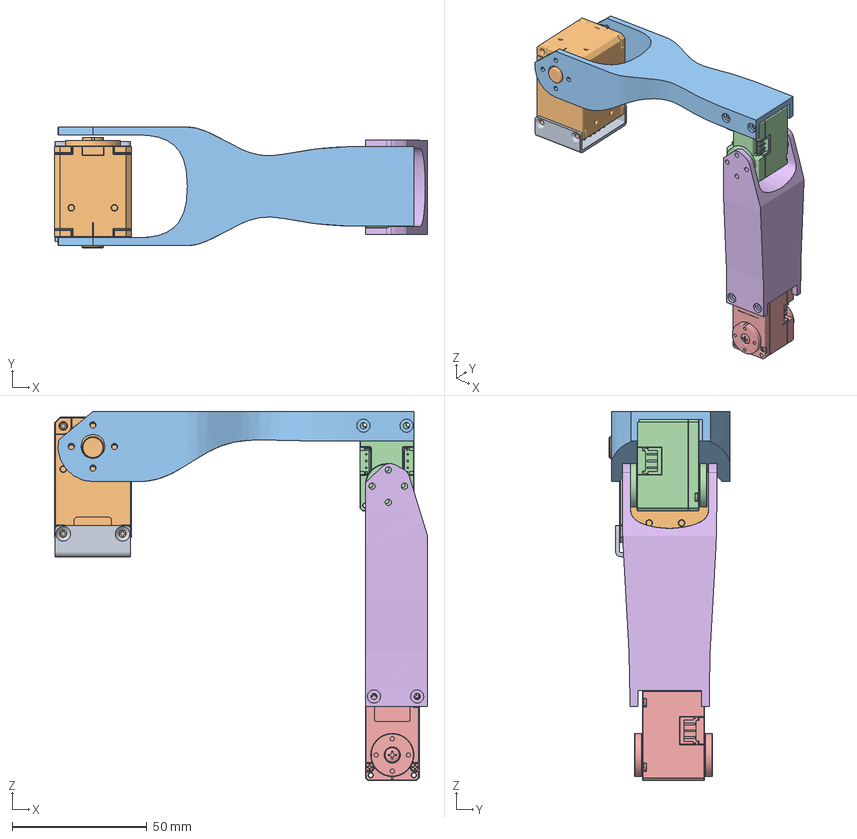
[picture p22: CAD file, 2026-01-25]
writing_robot_description/meshes/robot_arm.FCStd
138.3 x 44.9 x 136.9 mm
fr12_s102
XL-430_new
Follower_Shoulder_To_Elbow_binary
XL330-ID-3
XL330-ID4
Follower_Elbow_To_Wrist_Extension_binary

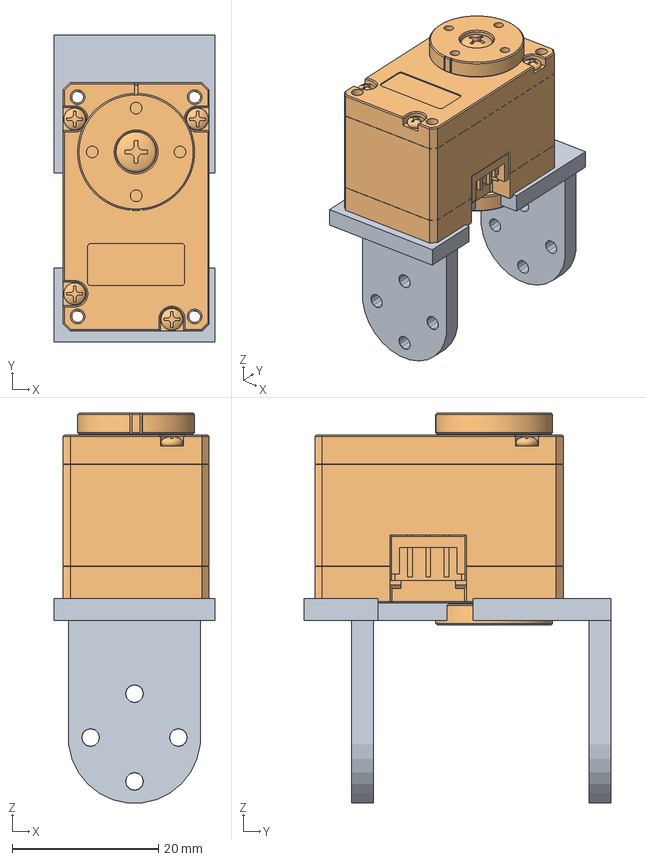
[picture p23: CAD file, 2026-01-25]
writing_robot_description/meshes/scratch_wrist_link.FCStd
22.0 x 42.0 x 53.3 mm
Follower_Elbow_To_Wrist_binary
XL,XC-330

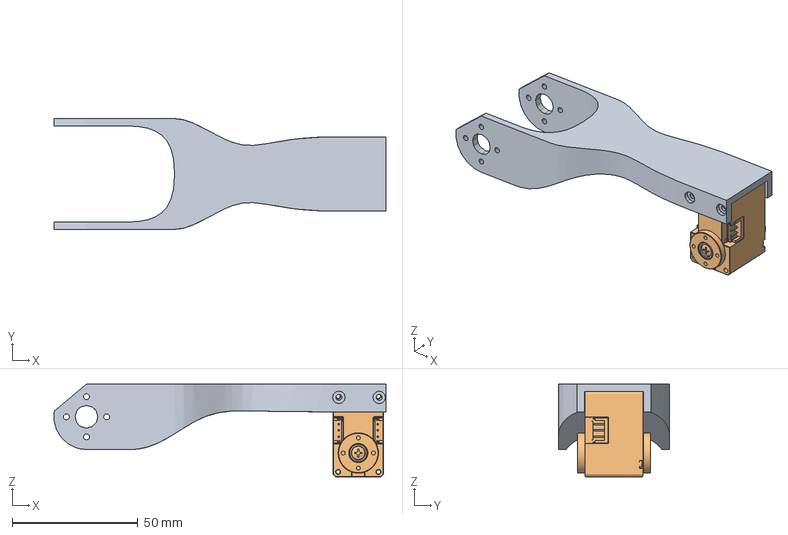
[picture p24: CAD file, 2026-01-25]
writing_robot_description/meshes/scratch_upper_arm_link.FCStd
131.9 x 44.0 x 36.9 mm
Follower_Shoulder_To_Elbow_binary
XL-330-ID3

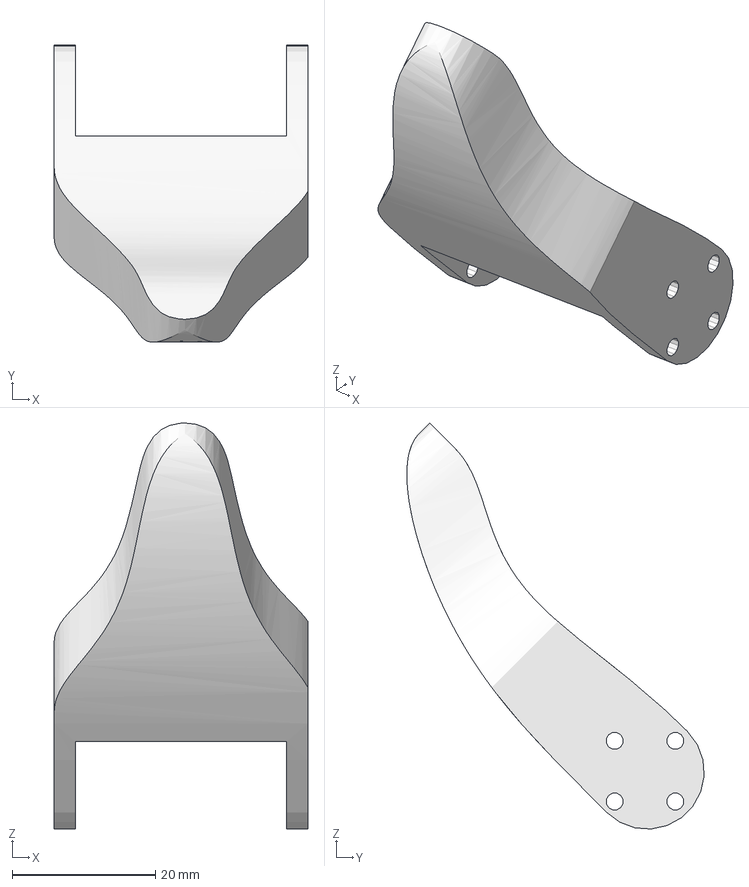
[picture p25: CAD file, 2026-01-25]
writing_robot_description/meshes/scratch_pen_link.FCStd
35.5 x 41.6 x 56.8 mm

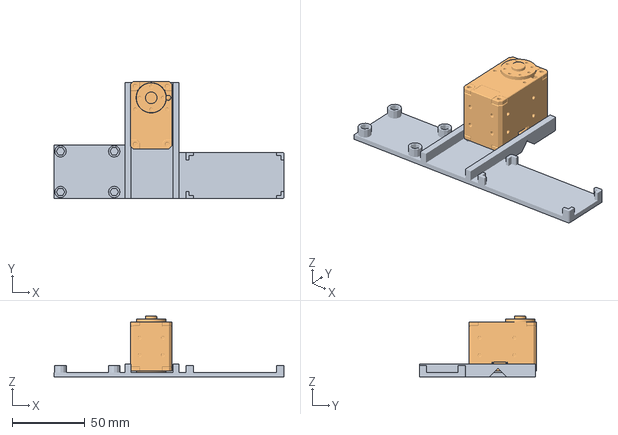
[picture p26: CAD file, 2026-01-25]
writing_robot_description/meshes/scratch_base_link.FCStd
158.5 x 80.6 x 41.9 mm
Follower_Base_binary
XL-430_new

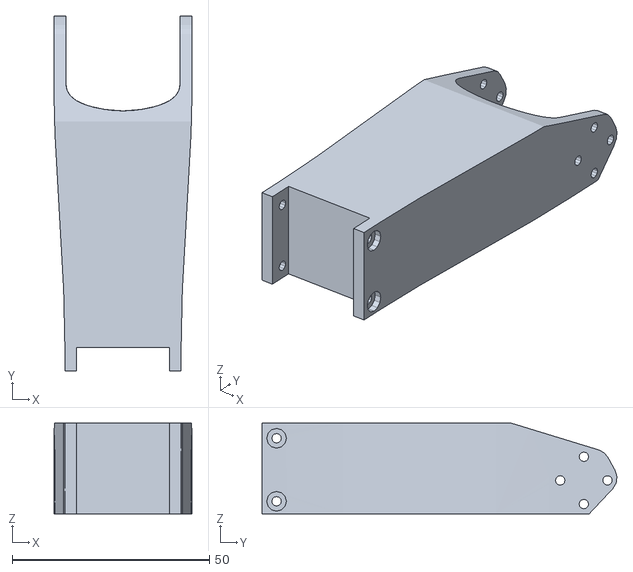
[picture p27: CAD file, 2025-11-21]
writing_robot_description/meshes/Follower_Elbow_To_Wrist_Extension_binary.stl
35.0 x 90.1 x 23.0

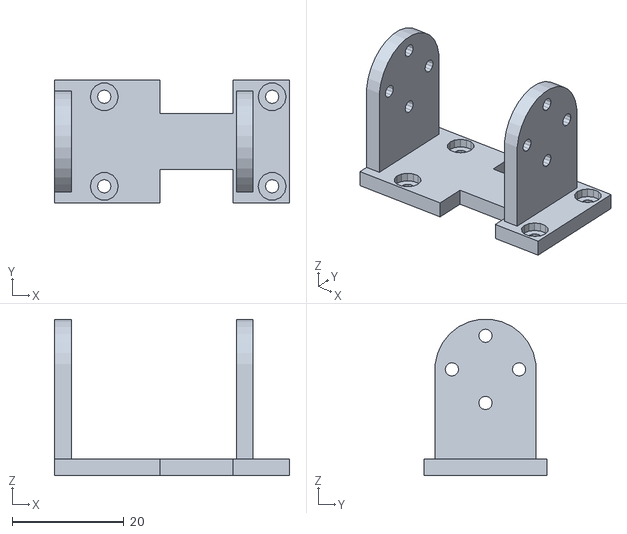
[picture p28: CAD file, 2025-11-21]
writing_robot_description/meshes/Follower_Elbow_To_Wrist_binary.stl
42.0 x 22.0 x 27.9

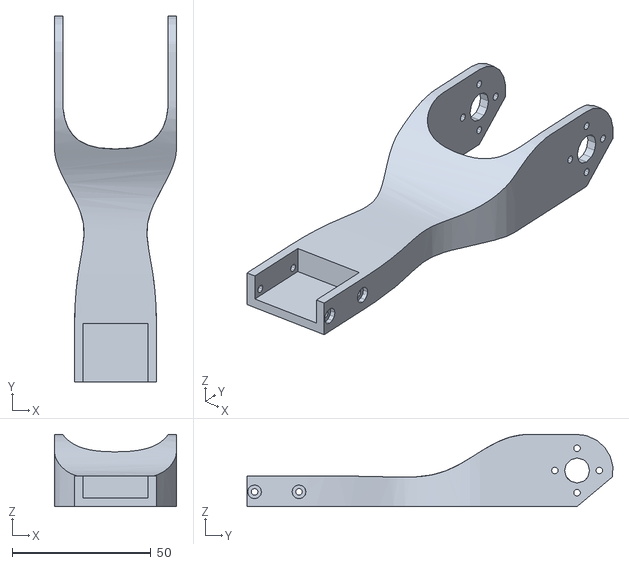
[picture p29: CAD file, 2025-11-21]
writing_robot_description/meshes/Follower_Shoulder_To_Elbow_binary.stl
44.0 x 131.9 x 26.0

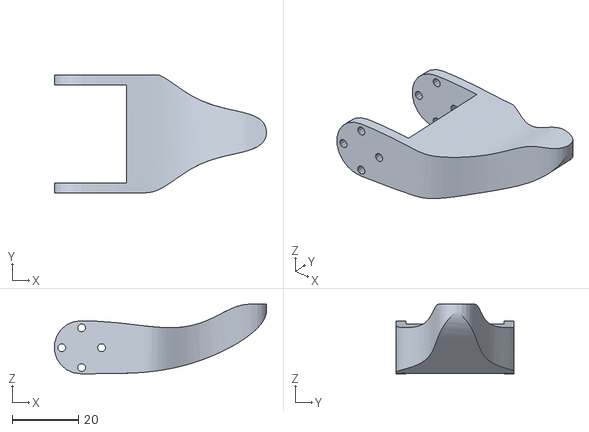
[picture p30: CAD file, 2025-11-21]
writing_robot_description/meshes/Follower_Gripper_Moving_Part_binary.stl
63.9 x 35.5 x 21.0

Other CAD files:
writing_robot_description/meshes/cup.v3.FCStd
writing_robot_description/meshes/scratch_hand_link.FCStd
writing_robot_description/meshes/scratch_hand_link_3.FCStd
writing_robot_description/meshes/Follower_Shoulder_Rotation_binary.stl
writing_robot_description/meshes/Follower_Base.STL
writing_robot_description/meshes/Follower_Base_binary.stl
writing_robot_description/meshes/Follower_Gripper_Static_Part_binary.stl
writing_robot_description/meshes/Follower_Shoulder_Rotation.STL
writing_robot_description/meshes/fr12_s102.stl
writing_robot_description/meshes/robot_arm.v2.FCStd
writing_robot_description/meshes/robot_arm.v3.FCStd

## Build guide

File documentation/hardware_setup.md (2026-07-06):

# Hardware Setup
This section describes the hardware setup including a detailed electrical layout.

## Sections
- [Hardware Overview](#hardware-overview): Outlines the hardware setup.
- [Bill of Materials](#bill-of-materials): What was purchased, motivation, and alternatives.
- [3D printing of robot parts](#3d-print-of-hardware): How to print the pieces.
- [Assembly of robot](#assembly-of-robot): how to assemble the robot.
- [Electrical Notes](#electrical-notes): Exactly how this robot was wired with additional notes.
- [Learnings and Next Steps](#learnings-and-next-steps): What did we learning in assemblying this robot and areas of improvement.

## Hardware Overview
The Koch v1.1 follower arm is a 6-degrees of robotic arm with the links illustrated as illustrated below. It is powered by four Dynamixel [XL330](https://en.robotis.com/shop_en/item.php?it_id=902-0163-000)'s and two Dynamixel [XL430](https://emanual.robotis.com/docs/en/dxl/x/xl430-w250/) servos. The controlling hardware is a combination of an [OpenRB 150](https://emanual.robotis.com/docs/en/parts/controller/openrb-150/) and a [Raspberry Pi 5](https://www.raspberrypi.com/products/raspberry-pi-5/). The two types of servos operate at different voltages so in addition to a [Robotis U2D2](https://en.robotis.com/shop_en/item.php?it_id=902-0145-001) we also are leveraging a Buck converter to step down the 12V to 5v+ for the XL330s. This project also includes sensors to measure the input electrical current. To that end, we are using IN219 and INA226 current sensors. The measurement of current is optional to the environment, but some of the analysis is greatly enhanced with it.

<p align="center">
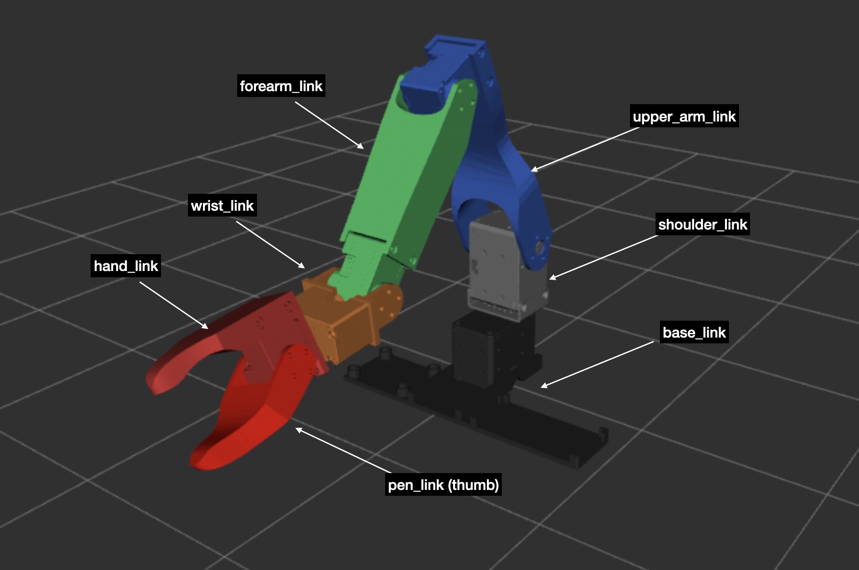
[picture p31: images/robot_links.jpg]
arm anotated
  
</p>
The joints of the robot are shown in the following diagram.
<p align="center">
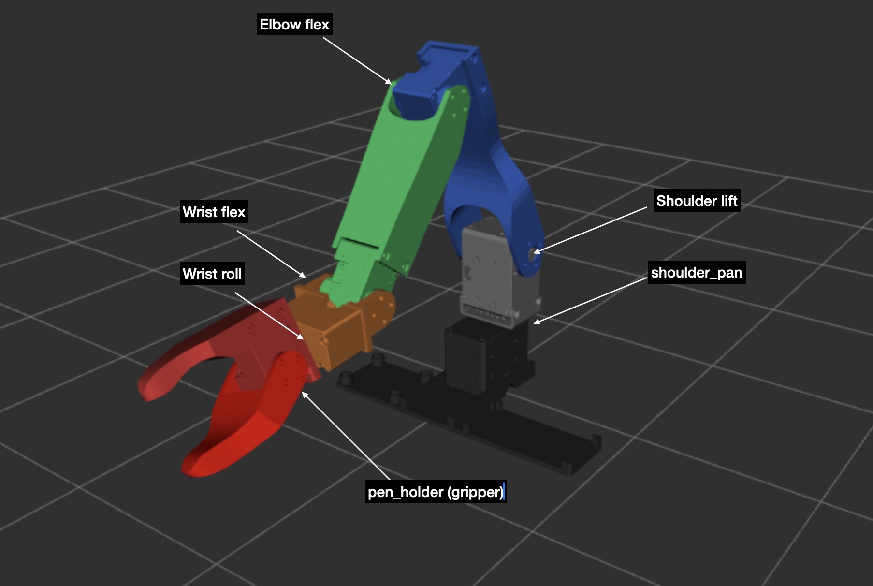
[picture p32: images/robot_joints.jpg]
arm anotated joins
  
</p>

## Bill of Materials
Koch v1.1 6-DOF Robotic Arm — Bill of Materials

> **Note:** Prices are approximate and subject to change. Spares are recommended for sensors and buck converters due to sensitivity during assembly and testing.

## Core Computing

| Qty | Component | Description | Link | Unit Price | Total |
|-----|---|---|---|---|---|
| 1 | 8GB Raspberry Pi 5 | main compute for robot arm | [Amazon B0CVR1LP7G](https://www.amazon.com/dp/B0CVR1LP7G) | $180 | $180 |
| 1 | Raspberry Pi 256GB SD Card | Storage for Raspberry Pi OS and ROS2 workspace | [Amazon B09X7CRKRZ](https://www.amazon.com/dp/B09X7CRKRZ) | ~$25 | ~$25 |
| 1 | NVIDIA Jetson Orin Nano Super Developer Kit | Optional: replaces Raspberry Pi; required for RViz visualization | [Amazon B0BZJTQ5YP](https://www.amazon.com/dp/B0BZJTQ5YP) | $245 | $245 |
| 1 | Case for NVIDIA Jetson Orin Nano | Protective enclosure for Jetson | [Amazon B0CG38BS5S](https://www.amazon.com/dp/B0CG38BS5S) | $22 | $22 |

## Dynamixel Servos and controller

| Qty | Component | Description | Link | Unit Price | Total |
|-----|---|---|---|---|---|
| 1 | OpenRB 150 | controller for servos | [Robotis](https://robotis.us/openrb-150) | $30 | $30 | 
| 4 | XL330-M288-T | Wrist, shoulder, hand and gripper servos | [Robotis](https://en.robotis.com/shop_en/item.php?it_id=902-0163-000) | $24 | $96 |
| 1 | XL330-M077-T | Substitute for XL330-M288-T if out of stock (not for elbow lift) | [Robotis](https://en.robotis.com/shop_en/item.php?it_id=902-0162-000) | $24 | $24 |
| 2 | XL430-W250-T | Higher-torque servos for base rotation and elbow lift | [Robotis](https://en.robotis.com/shop_en/item.php?it_id=902-0135-000) | $24 | $48 |

## Dynamixel Interface & Cabling

| Qty | Component | Description | Link | Unit Price | Total |
|-----|---|---|---|---|---|
| 1 | U2D2 PHB Set | USB-to-Dynamixel interface board set | [Robotis](https://en.robotis.com/shop_en/item.php?it_id=902-0145-001) | $20 | $20 |
| 1 | Robot Cable-X3P 180mm (Pack of 10) | Servo daisy-chain cables | [Robotis](https://en.robotis.com/shop_en/item.php?it_id=903-0249-000) | $20 | $20 |
| 1 | Robot Cable-X3P 180mm (Convertable) (Pack of 10) | used with to extend reach of cables with SMPS2Dynamixel apdapter | [ROBOTIS](https://en.robotis.com/shop_en/item.php?it_id=903-0251-000) | $20 | $20 | 
| 1 | ROBOTIS SMPS2Dynamixel Power Adapter| for extending reach of Robotis cables | https://www.robotshop.com/products/robotis-smps2dynamixel-power-adapter-smps-to-dynamixel | $10 | $10 |

## Power

| Qty | Component | Description | Link | Unit Price | Total |
|-----|---|---|---|---|---|
| 1 | 12V Power Supply 10A | Main power supply for OpenRB150, XL330s, XL430 servos | [Amazon B07MXXXBV8](https://www.amazon.com/dp/B07MXXXBV8) | ~$20 | ~$20 |
| 1+ | Buck Converter (DC-DC Step-Down) | Steps 12V down to 5V for XL330 servos and logic; buy several for spares | [Amazon B085T73CSD](https://www.amazon.com/Converter-1-25-36V-Voltage-Regulator-Display/dp/B085T73CSD) | $15 (multi-pack) | $15 |

## Telemetry / Current Sensing

| Qty | Component | Description | Link | Unit Price | Total |
|-----|---|---|---|---|---|
| 2 | INA219 Current Sensor | I²C current/voltage monitoring; spares recommended | [Amazon B0FKBDX2R2](https://www.amazon.com/dp/B0FKBDX2R2) | $10 (pack) | $10 |
| 2 | INA226 Current Sensor R100| Higher-precision I²C power monitor; spares recommended | [Amazon B0FC656459](https://www.amazon.com/dp/B0FC656459) | $16 | $32 |
| 2 | INA226 Voltage Current Monitor 0-36V 20A Tester I2C IIC Power Monitoring Sensor Module | [Amazon B0DRNG1VKM](https://www.amazon.com/dp/B0DRNG1VKM) | $13 | $26 |
| 1 | ESP32 Dev Kit | Microcontroller for telemetry and sensor aggregation | [Amazon B0FNQVZJ6D](https://www.amazon.com/dp/B0FNQVZJ6D) | $20 | $20 |

## Prototyping & Wiring

| Qty | Component | Description | Link | Unit Price | Total |
|-----|---|---|---|---|---|
| 1 | Solderless Breadboard Kit | Full-size breadboard for circuit prototyping | [Amazon B08Y59P6D1](https://www.amazon.com/dp/B08Y59P6D1) | $10 | $10 |
| 1 | Mini Breadboard Kit | Small breadboards for compact sensor wiring | [Amazon B01KKE602W](https://www.amazon.com/dp/B01KKE602W) | $8 | $8 |
| 1 | 23AWG Breadboard Jumper Ribbon Cables Kit | Jumper wires for breadboard connections | — | $10 | $10 |

## Mechanical Mounting

| Qty | Component | Description | Link | Unit Price | Total |
|-----|---|---|---|---|---|
| 2 | C-Clamps | Secure robot base to work surface; size depends on your table | Local hardware store | ~$10 | ~$10 |

## Balance Related Hardware
The following are the components added to support the cup balancing effort.
| Qty | Component | Description | Link | Unit Price | Total |
|-----|---|---|---|---|---|
| 1 | IMU sensor | HiLetgo 3pcs GY-521 MPU-6050 MPU6050 3 Axis Accelerometer Gyroscope Module 6 DOF 6-axis Accelerometer Gyroscope Sensor Module 16 Bit AD Converter Data Output IIC I2C for Arduino | Amazon | ~$10 | ~$10 |
| 1 | ESP32 controller | HiLetgo ESP-WROOM-32 ESP32 ESP-32S Development Board 2.4GHz Dual-Mode WiFi + Bluetooth Dual Cores Microcontroller Processor Integrated with Antenna RF AMP Filter AP STA | Amazon | ~$10 | ~$10 |
| 1 | USB hub with external power | Atolla 4-Port USB 3.0 Hub with 4 Data Ports, 1 Smart Charging Port, Individual On/Off Switches and 5V/3A Adapter | Amazon | ~$20 | ~$20 |
| 1 | Luxonis Oak-D lite | 3d camera with inferencing capability | https://shop.luxonis.com/products/oak-d-lite-1 | https://www.luxonis.com | $150 | $150 |
| 1 | camera stand  | SMALLRIG 22" Magic Arm Clamp, Overhead Phone Mount Holder Stand, Flexible Desk Camera Mount, Articulating Friction Boom Arm, for POV Shot, Filming, Light, Webcam, Action Camera | Amazon | ~$10 | ~$10 |

---

## 3D Print of Hardware
There are a number of ways to print the various custom pieces of the robot arm. We have both printed pieces via a local 3D print and used the [Craftcloud](https://craftcloud3d.com/) service. The meshes used in this print are located [here](../writing_robot_description/meshes). These are derived as binary representations of the ones located in the original [koch v1.1](https://github.com/jess-moss/koch-v1-1/tree/main/hardware/follower/STL) version.

The Balance PID controller exercise requires an additional 3D printed cup. This is shown below. This is the third version of the cup which improved upon the other two designs by being more smoothly concave. Indeed cup v1 had a flat bottom which made it impossible for a robot (or a human) to balance the ball bearing.

<p align="center">
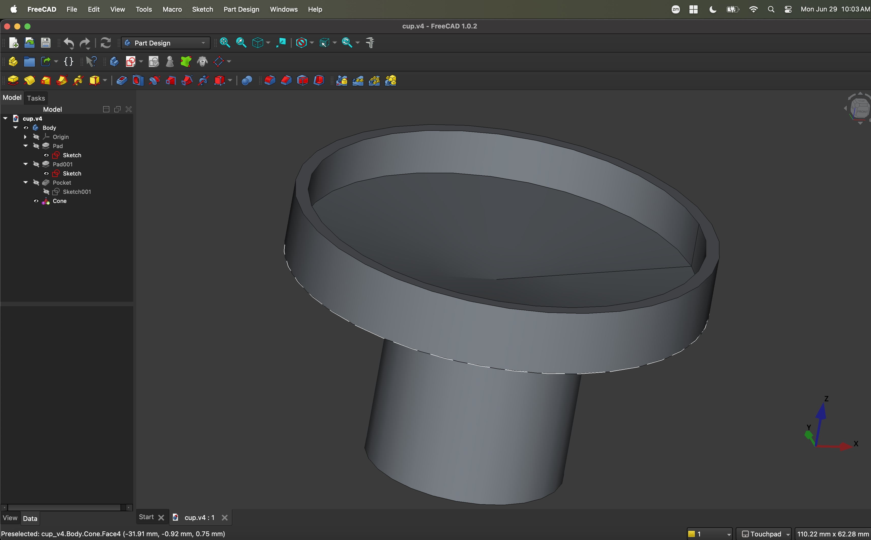
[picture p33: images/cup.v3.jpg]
cup v3
  
</p>

The STL and Free cad files for this version of the cup found as:
1. [cup.v3.FCStd](../writing_robot_description/meshes/cup.v3.FCStd),
2. [cup.v3-Body.stl](../writing_robot_description/meshes/cup.v3-Body.stl)

Note that the koch v1.1 hand is incapable of holding the cup without it rocking as the pitch changes. This is partly due to the design of the hand (or more accurately: the claw). Adding tape around the claw was unsuccessful in solving the issue. We respeted to tieing the base of the cup to the hand with a rubber band. 

## Assembly of Robot
- **Arm Assembly**: The basic assembly of the koch v1.1 robot is outlined in detail in the [Jess Moss Youtube video](https://www.youtube.com/watch?v=8nQIg9BwwTk) (follower assembly starts around 8:22 min into the video). The key divergence from this work is the shoulder link. In this version the XL430 servo is positioned upright (vs. horizontal) and we use a standard Robotis bracket (see BOM) instead of the one defined by Jess.
- **Anchoring of arm**: TBD
- **Electronic board enclosure**: The enclosure for the electronics is under development.
  <p align="center">
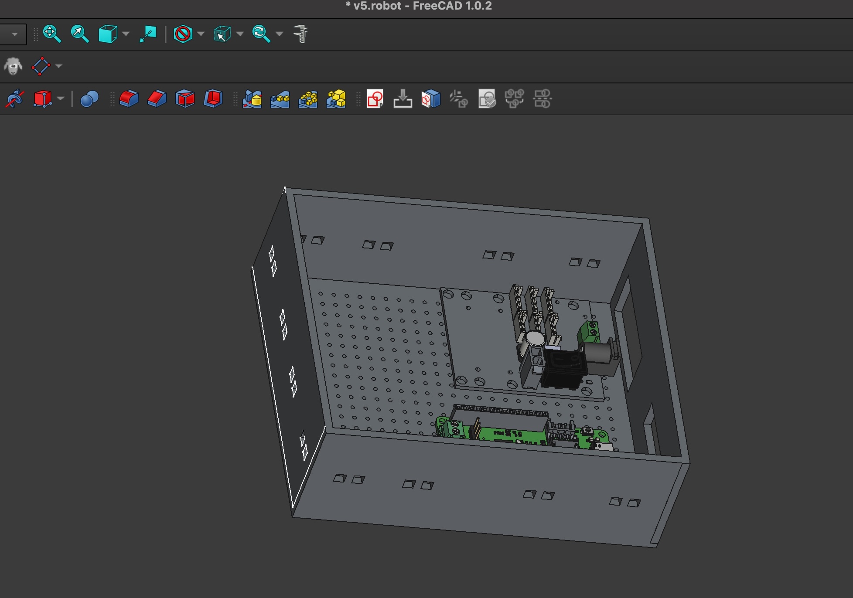
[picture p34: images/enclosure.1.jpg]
encosure view 1
  
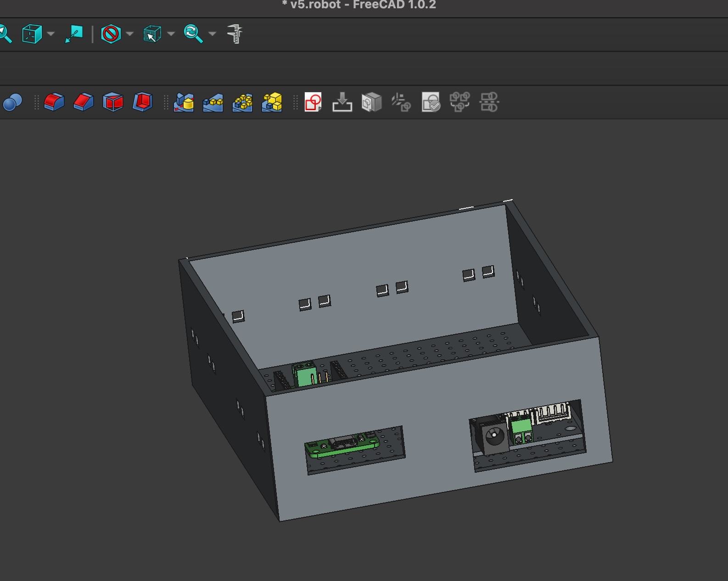
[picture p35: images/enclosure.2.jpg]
encosure view 2
  
</p>

- **Electrical wiring**: See below

## Electrical Notes

The following is an electrical schematic of the robot with the external current sensors. Note that although you can use the INA219 or the INA226 sensors we recommend the INA226 sensors with R002 resistors (vs either with R100 resistors). This ensures that the reading of the sensor can be larger than 1 amp (otherwise as the current gets that large the sensor maxes out on its reading).

<p align="center">
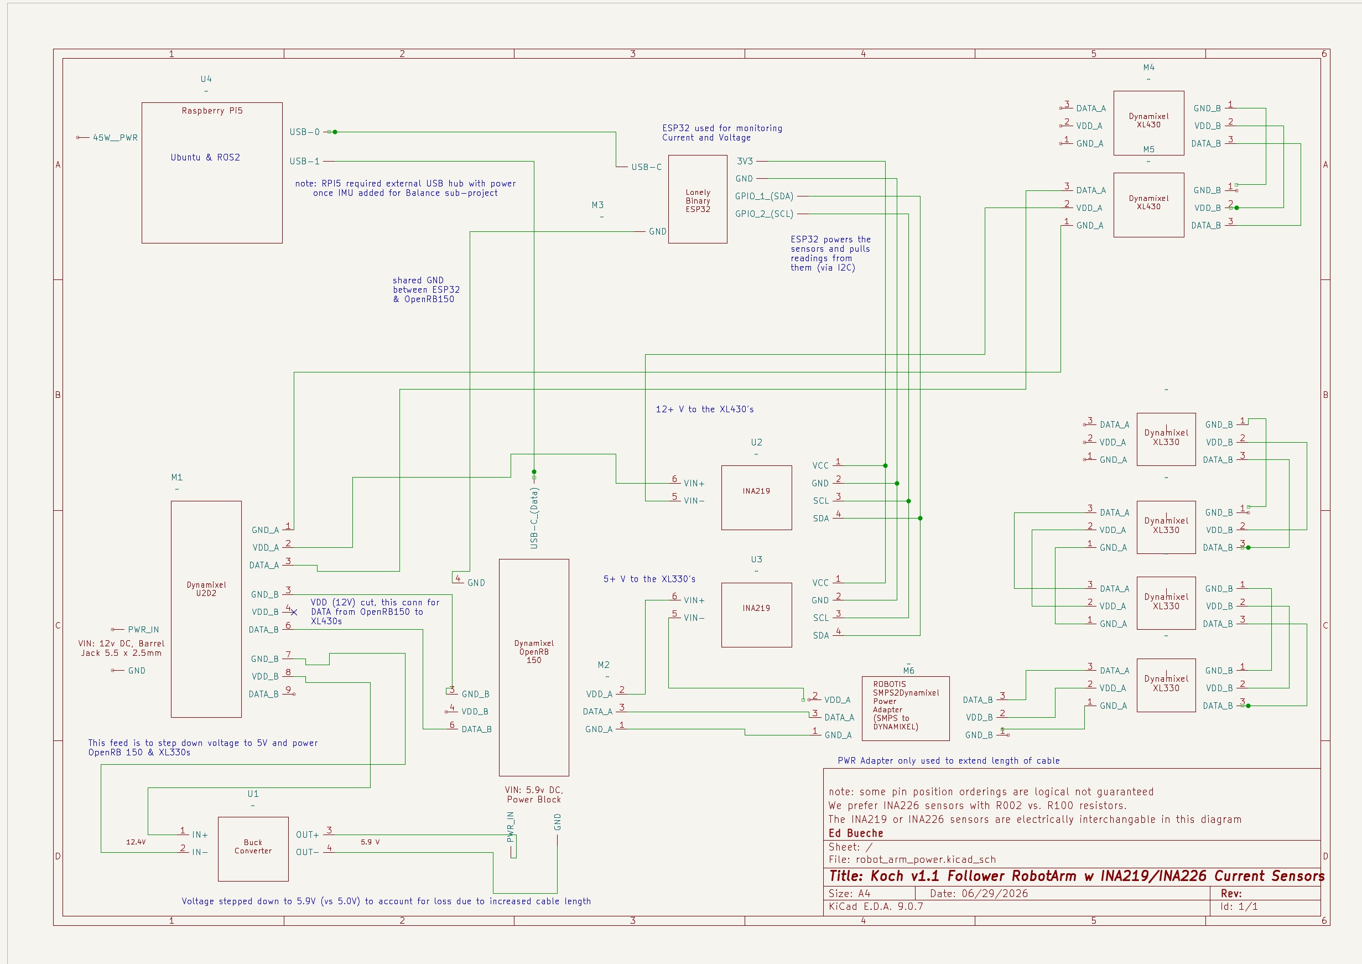
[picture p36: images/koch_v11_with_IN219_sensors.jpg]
electrical wiring
  
</p>

Those sensors are really optional for the running of the robot and are meant to provide deeper electrical insight. The following is a wiriing setup without those sensors.
<p align="center">
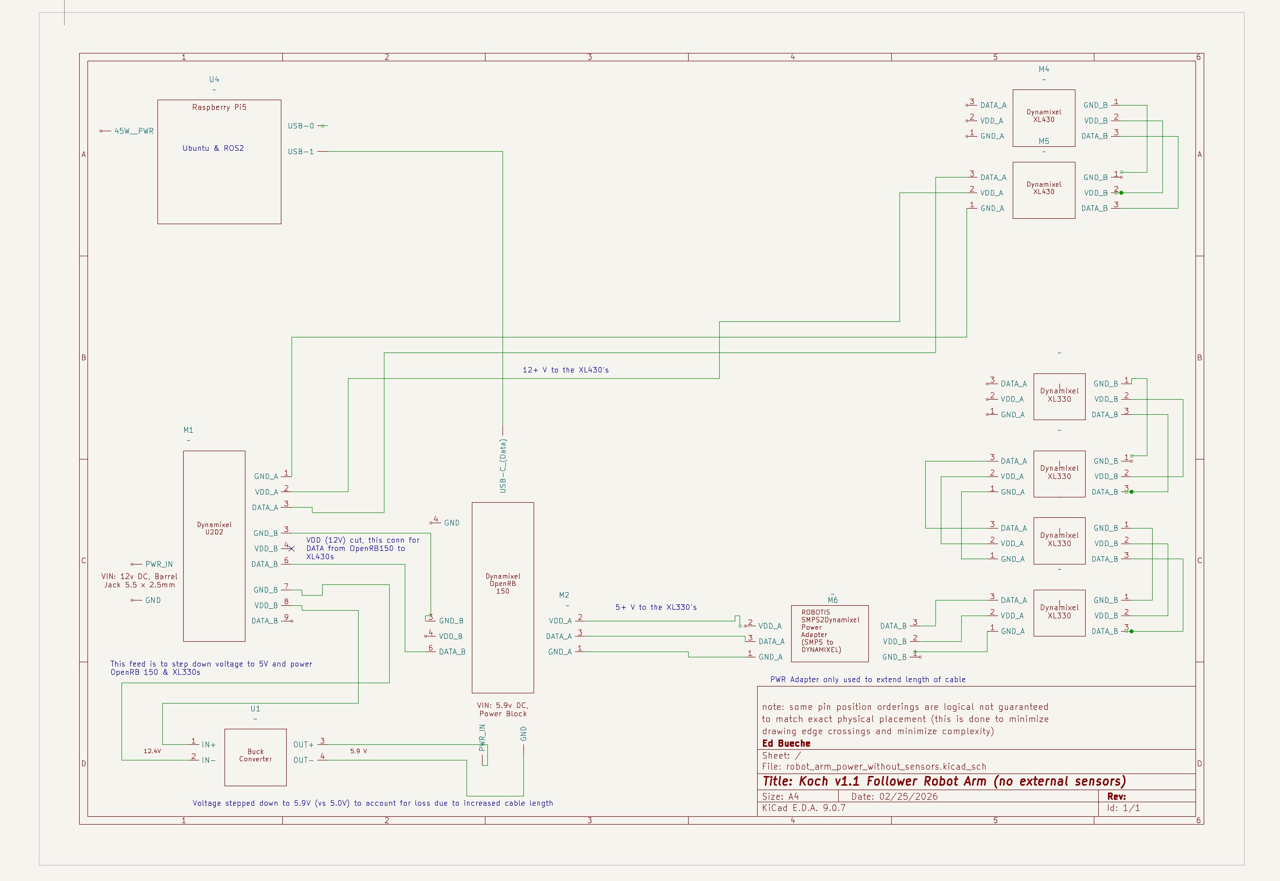
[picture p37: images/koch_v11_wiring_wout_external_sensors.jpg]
electrical wiring no external sensors
  
</p>

Some additional notes:
- **For the Balance project a USB hub with external power is required**: I still need to update the electrical diagrams to reflect this. The PI does not have enough juice to power the openRB150, the ESP32 for the power sensors, and the ESP32 for the IMU. Its possible to perhaps work with a single board (openRB150) but for simplicity of the sketches I didn't do that. This is left as an exercise to the reader.
 
- **Operating 12V and 5V servos on the same robot**: The XL430's are 12V and the XL330's operate on 5V. There are a number of ways to power these servo's and we decided to use a 12V power supply into the U2D2 and then feed some of that into a buck converter for the XL330's and openRB150. The OpenRB will feed data, VCC, and GND into the XL330 path but only Data and GND into the XL430 path. There is a connection from the U2D2 to the OpenRB that has the VCC line physically cut for this. This allows the U2D2-2-XL430 path to carry power, data, and gnd to the XL430's.
  
- **Cable Length issues - part 1 "range of motion"**: A single 180mm X3P cable from the OpenRB150 to the first XL330 isn't quite long enough to allow the joint with that XL330 to have adequate range of motion (see picture below). 7.75 inches ~= 200 mm, which is beyond the max size cable that (I think) Robotis supports. So we looped in a light weight SMPS2Dynamixel power adapter that allows two 180mm X3P convertable cables to be used effectively doubling the length. Although that power adapter can accept external power it also can be powered just by the incoming cables. There are other ways to extend the reach of these cables (higher guage cable). 
<p align="center">
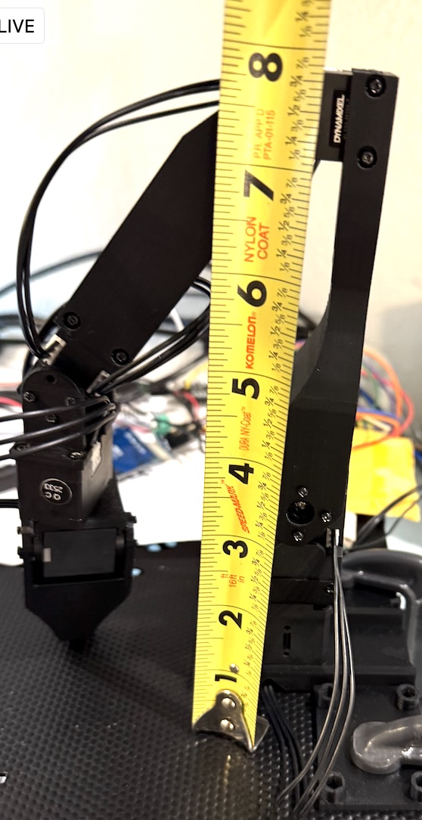
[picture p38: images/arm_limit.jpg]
arm limt
  
</p>

- **Cable Length issues - part 2 "splicing in VIN+/-"**: We used two different ways of splicing in the IN219 VIN+/- connection. In one case we physically cut the power cable and terminated the ends with ferrules and fed these into the power block for the IN219s. But the range of motion and/or circuit board placement becomes an issue and a longer set of wires is needed. So, in the other we used the female end of a breadboard jumper cable into the IN219 but male end into the X3P connector. If the jumper cables were not at least 23AWG then there would be issues with powering the servos. The longer the cable the more power is lost especially when more current is needed for certain poses. The 23AWG guage cables help but we also upped the voltage out of the buck converter to 5.9V ensure all XL330's would see 5+ volts and not error out due to lack of voltage. Theoretically, this will lead to higher temperatures when running the Servo's but I haven't measured anything significant on this front.
  
- **Shared ground**: The ESP32 (used for current monitoring), the openRB150, and the servo's all share GND.
  
- **The 12V input to the U2D2 can provide up to 10 amps**. This should support the peak possible current pull from all of the components but I'm far off of that at the current moment.
  
## Learnings and next steps
There are numerous learnings and next steps:
- **The Koch v1.1 base link is not appropriate for the hardware chosen**: Its the wrong size and is not flexible to handle change over time. It was designbed for different controllers and other hardware. At the moment we are keeping it and designing a separate electronics enclosure (shown above).

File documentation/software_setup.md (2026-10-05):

# Sofware Setup for Robot Arm

This section describes how to setup the software to run the koch_v11 follower on ros2. The ros2 environment configured and run on a docker image.

## Sections 
- [Underlying hardware and OS variations](#underlying-hardware-and-os-variations): This section briefly outlines some of the hardware/OS variations that this has been tested on.
- [Docker setup on host OS](#docker-setup-on-host-os): installing and setting up docker on the host os.
- [Docker image and container setup](#docker-image-and-container-setup): This section describes how to create the docker images needed for this project and how to startup and finish setting up the containers.
- [Dynamixel software changes](#dynamixel-software-changes): Outlines the changes made to the Dynamixel software to pull additional telemetry data from the servos on Ros2.
- [Simple simulation smoke test](#simple-smoke-test): After installing the software you can test a decent percentage of it with the display only test.
- [TODO list](#todo-list): some notes on changes to come.

## Underlying hardware and OS variations
- The robot software setup and operation has been tested on a Raspberry Pi5 running Ubuntu 22.04 (Jammy). 
- The robot software setup and rviz2 operation has been tested on an Nvidia Orin Nano dev kit also running Ubunto 22.04. Rviz is run on the Nano as the Raspberry pi is underpowered for simulation. In this setup rviz2 runs on the Nvidia and the ros2 robot interfacing software runs on the Pi. 

## Docker setup on host OS

1. After installing the OS on your Nvidia or Pi then install git.
```
$ sudo apt update
$ sudo apt install git -y
```

2. Configure git
```
$ git config --global user.name "Your Name"
$ git config --global user.email "youremail@example.com"
```
3. make your project directory and clone this project's source 

```
$ mkdir -p ~/robot_ws
$ cd ~/robot_ws
$ git clone https://github.com/bueche/ros2_robot_arm.git src
```
The act of cloning it to a directory named `src` is intentional. Also, this `robot_ws` will be mirrored into the docker container.

### Docker Installation

See https://docs.docker.com/engine/install/ubuntu/ for more details.

On Nvidia do some additional docker setup steps to enable the Nvidia container runtime

```
$ sudo apt-get install nvidia-container-toolkit
$ sudo nvidia-ctk runtime configure --runtime=docker
$ sudo systemctl restart docker
$ sudo docker info | grep -i runtime
 Runtimes: runc io.containerd.runc.v2 nvidia
 Default Runtime: nvidia
```

## Docker image and container setup
1. Build the docker image

In the example below we assume that the calling user id is 1000.

```
$ id | grep 1000
uid=1000(arduino) gid=1000

```
If so, then run.

```
$ cd ~/robot_ws/src
$ # create base ros 
$ sudo docker build --platform linux/arm64 -t ros-jazzy-arm64 --load  --no-cache -f docker/Dockerfile.ros-jazzy-arm64 .
$ # create image upon base
$ sudo docker build --platform linux/arm64 -t robot-jazzy-arm64 --load  --no-cache -f docker/Dockerfile.jazzy.arm64  .
```

if not, as in the example below, the user id that cloned this environment has a UID and GID of 1002. Again, the default is 1000, so if different then pass in the alternative value (in this case 1002 ... see below).

```
$ cd ~/robot_ws/src
$ # create base ros 
$ sudo docker build --platform linux/arm64 --build-arg UID=1002 --build-arg GID=1002 -t ros-jazzy-arm64 --load  --no-cache -f docker/Dockerfile.ros-jazzy-arm64 .
$ # create image upon base
$ sudo docker build --platform linux/arm64 --build-arg UID=1002 --build-arg GID=1002 -t robot-jazzy-arm64 --load  --no-cache -f docker/Dockerfile.jazzy.arm64  .
```
This will run for a while and create the docker image.
```
$ docker image list
REPOSITORY           TAG       IMAGE ID       CREATED         SIZE
robot-jazzy-arm64   latest    7ad21e00ddc5   44 hours ago    5.52GB
ros-jazzy-arm64     latest    3756d0e83149   9 months ago    3.98GB
```
2. Start the container

Now when the container is initially started with the `docker/run.sh` script you must be running your terminal from within the windowed interface of the host device. This is due to the fact that the container is configured to be able to run windowed apps like `ms-code` and `rviz2`. TODO: This restriction should be removed optionally with a parameter.

```
$ cd ~/robot_ws/src
$ docker/run.sh 
```

Now there are three parameters to the `run.sh` script:
1. `-i` or `--image_name`: This is the input image name and the default is `robot-jazzy-arm64`.
2. `-c` or `--container_name`: This is what the running container will be named. The default is `robot_container`.
3. `-w` or `--workspace`: This is the name of the workspace that will be shared with the container file system. The default is `robot_ws` but that unlikely the name you gave to your workspace.

so lets suppose we want to call the container `robot_jazzy_container` and our workspace is `robot_jazzy_ws`, then the invocation is:

```
$ cd ~/robot_ws/src
$ docker/run.sh -i robot-jazzy-arm64 -c robot_jazzy_container -w robot_jazzy_ws 
```

note: there may be some errors that print related to key setup failure. These can be ignored.

3. Run the post-container start script
There is a post-container script to run that will download some additional software and setup the environment. This should be done within the container.

```
$ cd robot_ws/src
$ls -lt additional_env_setup.sh 
-rwxrwxr-x 1 bueche bueche 3337 Feb 22 14:53 additional_env_setup.sh
$ bash  additional_env_setup.sh
```

### Dynamixel software changes
   - This ros2-based software requires some small enhancements to improve telemetry for the dynamixel servos. This involved modifying the [dynamixel_hardware_interface](https://github.com/ROBOTIS-GIT/dynamixel_hardware_interface) and [dynamixel_interface](https://github.com/ROBOTIS-GIT/dynamixel_interfaces) packages of Robotis. The changes are small. See the following PRs for more details.
      - [dynamixel_interface PR-10](https://github.com/ROBOTIS-GIT/dynamixel_interfaces/pull/10)
      - [dynamixel_hardware_interface PR-107](https://github.com/ROBOTIS-GIT/dynamixel_hardware_interface/pull/107)
    
These PRs are applied automatically to the Dynamixel software downloads done by the ` additional_env_setup.sh` noted above.

## Simple smoke test
It is possible to test a good percentage of the software setup by successful execution of the launch_display.
```
$ cd ~/robot_ws
$ colcon build --symlink-install
$ ros2 launch writing_robot_description display_launch.py

```
This will launch rviz with a display only version of the robot that can be controlled with the joint_state_publisher gui. Again, the hardware does not have to be wired to have this working. 
This is essentially a simple visual simulation, however, its not really appropriate on a raspberry pi or the arduino uno q as they are underpowered for rviz graphics.

<p align="center">
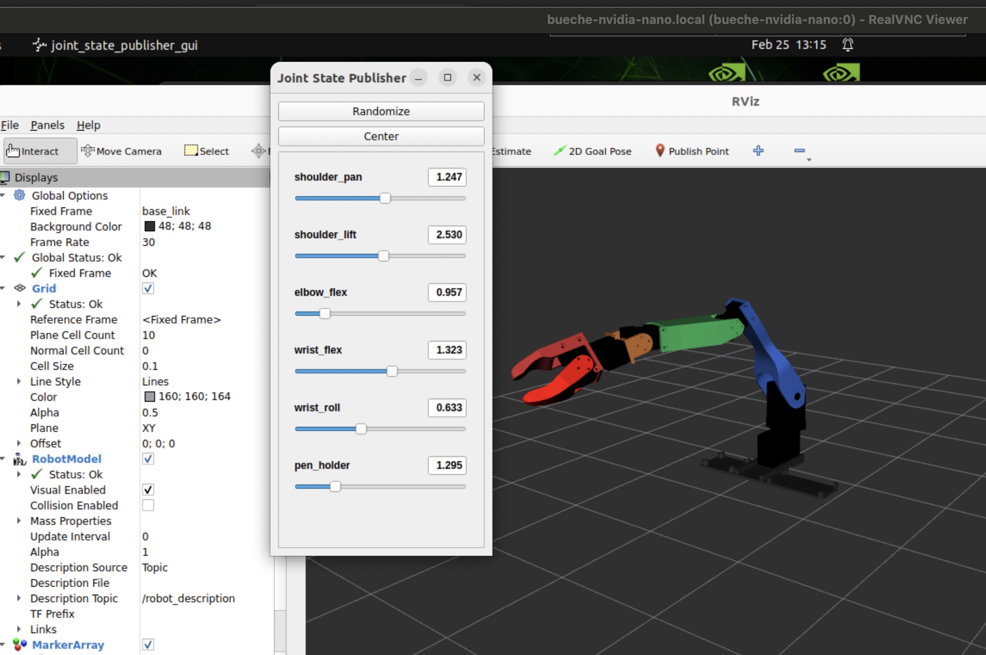
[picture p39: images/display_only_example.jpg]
display onlyd
  
</p>

## TODO list
- get amd64 containers tested on windows.
- clean up some noise in the scripts 
- add parameter to run.sh drop the need to have a gui interface

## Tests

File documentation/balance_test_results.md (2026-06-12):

# Balance Test Results
## Sections
## Balance Test results v1
### Summary
The following notes outline the test results so far and provide links to the details for each. 

The main metric for success in the V1 of the balancing effort is a "centered event". This is measured as 2 consecutive seconds in which the ball is within 15% of the center (pos < 0.15 on the unit circle). This event can happen only once for each pose as the test moves on to the next pose once it has been achieved. The following graph below charts the progress over the tests. 

<p align="center">
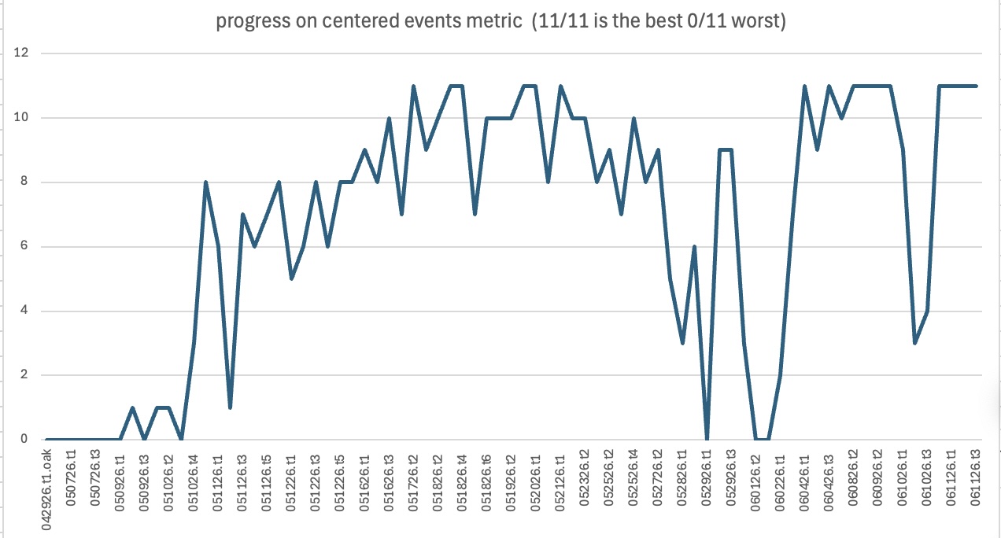
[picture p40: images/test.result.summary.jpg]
summary
  
</p> 

This particular metric is the most important at the moment, but doesn't tell the whole story. It has been possible to center the ball in all 11 poses, but achieving this is not consistent. Essentially, there is in general too much jitter in the movement cup and this causes the ball to fall out of the center once its there. The current effort is to reduce this jitter and this leads to experimentation that exposes bugs and otherwise unsuccessful tuning attempts. Hence, at times progress is much worse.

Another interesting metric to track is the percentage of ball coordinate samples that fall within the tight range (pos<15%) or the near range (pos<30%). This is a useful metric to know if one is making incremental progress even if the ball centered metric does not increase or stays the same. 

<p align="center">
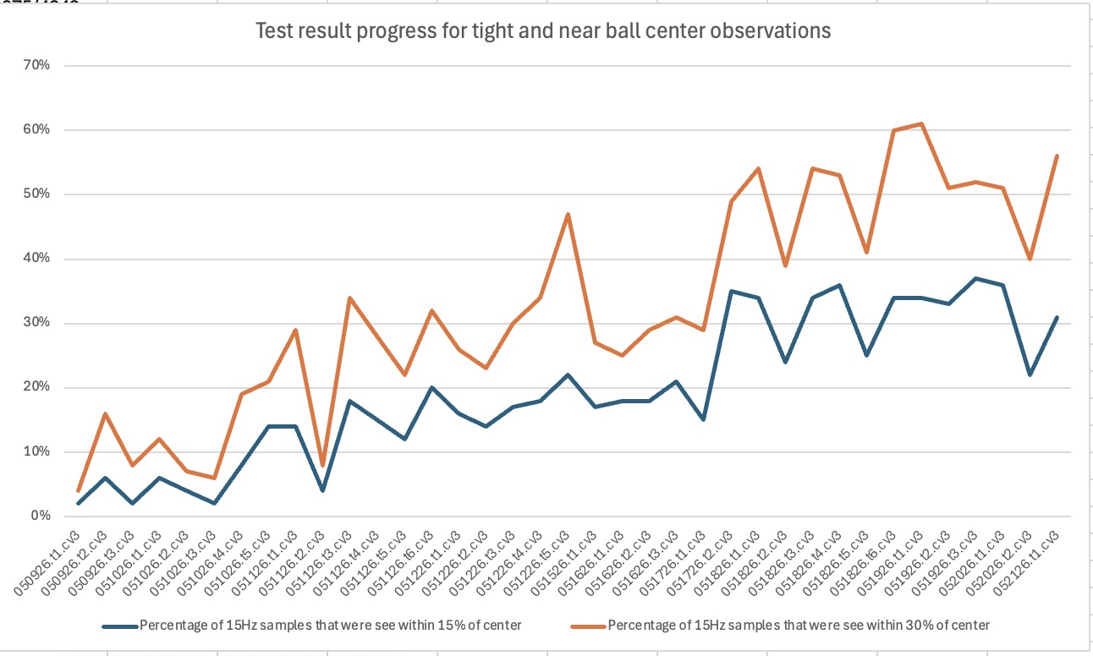
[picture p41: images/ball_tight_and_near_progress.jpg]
  
</p> 

### Detailed Test Result Conventions
There are several reporting conventions covered the results.
1. Each report file is tagged by date and test-number-of-the-day. We use YYMMDD.tN, where YY=2 digit year, MM = month, DD = day, and N = the test number of that day.
2. The raw test results are stored in a file with a naming convention: `test.results.YYMMDD.tN.cv3.txt`. Inside this file are the concatenated log output for (1) the `pose_test.py` utility, (2) the `wrist_balance_controller.py` node, (3) the `ball_balance_node.py`, (4) the `ball_detector_oak.py` or the `ball_detector_nvidia.py` (whichever was used in the test), and (5) the output from `system_watchdog.py`. In addition, some summary notes as to what was the main change from this test vs. the previous one are also provided.
3. The summary analysis is stored in a file with the naming convention: `test.analysis.YYMMDD.tN.cv3.txt`. This is created by running the `test_analysis.py` on the raw test results. This summarizes the entire test and also summarizes and ranks how each pose did.
4. Some corr (or correction) analysis is stored in a file with the naming convention: `test.corr.YYMMDD.tN.cv3.txt`. This provides a detailed analysis on how each correction did for a particular pose. Useful to spot the details of servo issues and to tune the PID values.
5. A  video of the rviz2 output is stored in a file with the naming convention: `test.video.YYMMDD.tN.cv3.txt`. 
6. Power logging output is stored in a file named `power_log_YYYYMMDD_NNNNNN.csv` this is a csv log output of the voltage, current, and temperature for the servos.

More details on the actual metric definitions can be found [here](./balance_metrics.md).

### Detailed Results by Date
#### 06-11-2026
- Summary: Finally some good D-term tuning tests for the XL430 shoulder lift. Three different configurations tried:
  -t1: D=8000 (same as yesterday's last run)
  -t2: D=7000 (to reduce the current load on the XL330s)
  -t3: D=9000

  All had 11 out of 11 poses reach balance. So the difference was more about how many corrections it took to get there:
  - D=7000 : 126 corrections
  - D=8000 : 112 corrections
  - D=9000 : 109 corrections

  In addition, we added a new analysis program to compute to the peak-to-peak amplitude for the shoulder lift. This is discussed more in this [Robotis discord thread](https://discord.com/channels/1377230275393884170/1439850230475526195/threads/1512555080572866692). A lower amplitude means less jitter and fewer situations where the ball is bouncing around in the cup (more stable). here for example in pose 5 (smaller is better):
  - D=7000 pose 5: 0.012272 rad
  - D=8000 pose 5: 0.012272 rad
  - D=9000 pose 5: 0.009204 rad

The full result comparison were as follows:
```
D=7000

Pose  Name                           Dur  Corrs   SL_pp_rad  SL_pp_deg   Tight%   Near%  Overshoot
--------------------------------------------------------------------------------------------------
   1  pose 1 - initial              16.6      9    0.013806      0.791    22.7%   29.6%       1142
   2  pose 2 -tilt cup right        18.9     12    0.010738     0.6152    31.6%   48.9%        681
   3  pose 3 - tilt cup left        16.3     10    0.010738     0.6152    31.2%   35.6%        710
   4  pose 4 - center               16.8     10    0.012272     0.7031    43.3%   59.0%        678
   5  pose 5 - forward              17.4     11    0.012272     0.7031    17.0%   27.1%       1269
   6  pose 6 - back                 18.4     12    0.019941     1.1425    38.0%   49.0%        935
   7  pose 6 - center               24.7     18    0.061359     3.5156    26.9%   61.2%        956
   8  pose 7 - tilt cup right       22.0     15    0.012272     0.7031    34.2%   50.5%       1015
   9  pose 8 - tilt cup left        17.8     10    0.012272     0.7031    25.2%   33.7%        841
  10  pose 9 - back                 15.5      9     0.01534     0.8789    34.6%   40.2%        925
  11  pose 10 - center              83.8     24    0.061359     3.5156    11.9%   15.8%       7056

D=8000

Pose  Name                           Dur  Corrs   SL_pp_rad  SL_pp_deg   Tight%   Near%  Overshoot
--------------------------------------------------------------------------------------------------
   1  pose 1 - initial              16.2      8    0.012272     0.7031    18.2%   21.9%       1212
   2  pose 2 -tilt cup right        20.1     13    0.012272     0.7031    32.4%   56.9%        683
   3  pose 3 - tilt cup left        19.7     13    0.013806      0.791    31.9%   38.8%        795
   4  pose 4 - center               19.1     12    0.012272     0.7031    68.3%   76.7%        425
   5  pose 5 - forward              17.1     10    0.012272     0.7031    17.7%   23.0%       1312
   6  pose 6 - back                 14.5      8     0.01534     0.8789    31.1%   34.7%        874
   7  pose 6 - center               19.2     12    0.058291     3.3398    32.2%   49.2%        976
   8  pose 7 - tilt cup right       24.5     18    0.013806      0.791    28.8%   41.5%       1275
   9  pose 8 - tilt cup left        24.1     17     0.01534     0.8789    22.9%   46.2%       1025
  10  pose 9 - back                 17.0     10    0.016874     0.9668    41.4%   50.0%        639
  11  pose 10 - center              62.8      7    0.059825     3.4277    84.1%   86.3%        857

D=9000

Pose  Name                           Dur  Corrs   SL_pp_rad  SL_pp_deg   Tight%   Near%  Overshoot
--------------------------------------------------------------------------------------------------
   1  pose 1 - initial              13.8      6    0.010738     0.6152    21.2%   23.6%        993
   2  pose 2 -tilt cup right        21.9     15    0.010738     0.6152    28.5%   35.4%       1268
   3  pose 3 - tilt cup left        18.4     11    0.010738     0.6152    25.0%   29.2%        975
   4  pose 4 - center               17.7     11    0.010738     0.6152    70.0%   81.9%        314
   5  pose 5 - forward              17.1     10    0.009204     0.5274    21.7%   33.9%       1128
   6  pose 6 - back                 19.1     12    0.018407     1.0546    44.6%   53.0%        858
   7  pose 6 - center               13.4      7    0.059825     3.4277    28.8%   33.9%        885
   8  pose 7 - tilt cup right       17.9     11     0.01534     0.8789    29.0%   34.3%        853
   9  pose 8 - tilt cup left        15.9     10    0.010738     0.6152    23.0%   26.8%       1145
  10  pose 9 - back                 22.9     17    0.018407     1.0546    28.7%   39.1%       1386
  11  pose 10 - center              57.8     15    0.059825     3.4277    75.0%   78.2%       1254
```
So it looks like for now D=9000 is the best. but this causes the XL330 servos to work harder sometimes and the voltage to sag. I will study this in more detail as time progresses.

- Best run: X out of 11
- Raw test results: [here](https://drive.google.com/drive/folders/1_ny9C2bt0pQm7SO0CW-gZ2vh3djyG4CG)

#### 06-10-2026
- Summary: The goal for this day was to work out the best Position D-term value for the XL430 powering the shoulder lift joint. However, some timing and protocol issues occurred between the PI and the Nano.  This caused the results to be terrible until it was fixed. The symptoms were picked up by the watchdog as messages that should have been flowing to the PI from the Nano were not:

```
[INFO] [1781125482.725336968] [system_watchdog]: === System Watchdog ===
  /ball/position: STALLED 6.3s  (msgs=4088)
  /ball/cup_detected: STALLED 6.3s  (msgs=4088)
  ✅ /imu/balance_error: 50.0Hz  max_gap=21ms  spikes=0  msgs=17500
  /imu/balance_cmd: STALLED 45.9s  (msgs=2911)
  ✅ /imu/is_stable: 50.0Hz  max_gap=22ms  spikes=0  msgs=17500
  /balance_enabled: STALLED 45.8s  (msgs=26)
  ✅ /joint_states: 100.0Hz  max_gap=12ms  spikes=0  msgs=34999
  ⚠️  /ball/image: 0.0Hz  max_gap=340662ms  spikes=1  msgs=8
  Pipeline latency: calibrating...
  Overall: ⚠️  ISSUES DETECTED
[INFO] [1781125487.725362755] [system_watchdog]: === System Watchdog ===
  /ball/position: STALLED 11.3s  (msgs=4088)
  /ball/cup_detected: STALLED 11.3s  (msgs=4088)
  ✅ /imu/balance_error: 50.0Hz  max_gap=21ms  spikes=0  msgs=17750
  /imu/balance_cmd: STALLED 50.9s  (msgs=2911)
  ✅ /imu/is_stable: 50.0Hz  max_gap=22ms  spikes=0  msgs=17750
  /balance_enabled: STALLED 50.8s  (msgs=26)
  ✅ /joint_states: 100.0Hz  max_gap=12ms  spikes=0  msgs=35499
  /ball/image: STALLED 9.7s  (msgs=8)
  Pipeline latency: calibrating...
  Overall: ⚠️  ISSUES DETECTED
[INFO] [1781125492.725338005] [system_watchdog]: === System Watchdog ===
  /ball/position: STALLED 16.3s  (msgs=4088)
  /ball/cup_detected: STALLED 16.3s  (msgs=4088)
  ✅ /imu/balance_error: 50.0Hz  max_gap=21ms  spikes=0  msgs=18000
  /imu/balance_cmd: STALLED 55.9s  (msgs=2911)
  ✅ /imu/is_stable: 50.0Hz  max_gap=22ms  spikes=0  msgs=18000
  /balance_enabled: STALLED 55.8s  (msgs=26)
  ✅ /joint_states: 100.0Hz  max_gap=13ms  spikes=0  msgs=35999
  /ball/image: STALLED 14.7s  (msgs=8)
  Pipeline latency: calibrating...
  Overall: ⚠️  ISSUES DETECTED

```
The first fix was to change the Nano to use `chrony` instead of `systemd-timesyncd` and then to have the Nano use the PI as a time sync server (this would align their clocks better).

This got the messages flowing but still at a reduced rate. On the pi (receiving end):

```
ubuntu@bueche-rpi5:~/robot_ws$ ros2 topic hz /ball/position
average rate: 10.655
	min: 0.011s max: 0.336s std dev: 0.09442s window: 11
average rate: 7.787
	min: 0.007s max: 0.437s std dev: 0.12979s window: 19
average rate: 8.145
	min: 0.007s max: 0.437s std dev: 0.11568s window: 30
average rate: 8.315
	min: 0.007s max: 0.437s std dev: 0.11049s window: 39
average rate: 8.074
	min: 0.007s max: 0.437s std dev: 0.11328s window: 46
average rate: 8.102
	min: 0.006s max: 0.437s std dev: 0.11070s window: 56
average rate: 8.174
	min: 0.006s max: 0.437s std dev: 0.10814s window: 65
average rate: 7.900
	min: 0.005s max: 0.483s std dev: 0.11941s window: 73
average rate: 8.168
	min: 0.005s max: 0.483s std dev: 0.11787s window: 84
^Cubuntu@bueche-rpi5:~/robot_ws$ ros2 topic hz /ball/image
average rate: 0.323
	min: 1.952s max: 4.239s std dev: 1.14336s window: 2

```
vs. on the Nano:
```
ubuntu@bueche-nvidia-nano:~/robot_ws$ ros2 topic hz /ball/position
average rate: 12.011
	min: 0.081s max: 0.084s std dev: 0.00076s window: 13
average rate: 11.999
	min: 0.081s max: 0.084s std dev: 0.00058s window: 25
average rate: 11.996
	min: 0.081s max: 0.084s std dev: 0.00056s window: 37
average rate: 11.994
	min: 0.081s max: 0.084s std dev: 0.00051s window: 49
average rate: 11.994
	min: 0.081s max: 0.084s std dev: 0.00047s window: 61
average rate: 11.992
	min: 0.081s max: 0.084s std dev: 0.00046s window: 73
average rate: 11.992
	min: 0.081s max: 0.084s std dev: 0.00047s window: 85
average rate: 11.992
	min: 0.081s max: 0.084s std dev: 0.00046s window: 97
^Cubuntu@bueche-nvidia-nano:~/robot_ws$ ros2 topic hz /ball/image
average rate: 3.998
	min: 0.250s max: 0.250s std dev: 0.00027s window: 5
average rate: 3.997
	min: 0.250s max: 0.251s std dev: 0.00041s window: 9
average rate: 3.997
	min: 0.250s max: 0.251s std dev: 0.00037s window: 13
average rate: 3.997
	min: 0.250s max: 0.251s std dev: 0.00035s window: 17
average rate: 3.997
	min: 0.250s max: 0.251s std dev: 0.00034s window: 21
average rate: 3.996
	min: 0.250s max: 0.251s std dev: 0.00034s window: 25
```
To fix this the pi's udp buffer size was increased and the host rebooted:
```
bueche@bueche-rpi5:~$ sudo sysctl -w net.core.rmem_max=26214400
sudo sysctl -w net.core.rmem_default=26214400
[sudo] password for bueche: 
net.core.rmem_max = 26214400
net.core.rmem_default = 26214400
bueche@bueche-rpi5:~$ sync
bueche@bueche-rpi5:~$ reboot
```
and this cleared up the issue.

Aside from the last run (t4), all tests should be considered hosed.

- Best run: 11 out of 11 (last one ... others were terrible)
- Raw test results: [here](https://drive.google.com/drive/folders/1NihKmjOPDQXxpBmLHh7cGpb9e3qIfNjM)

#### 06-09-2026
- Summary:  This is the start of trying to tune the XL430 for the shoulder lift. Previous analysis has shown that it needs some damping during the pid phase. 

  -t1: initiate the servo tuning with the XL430. should have the same parameters as the default so achieve the same result as yesterday. D=4000
  - t2: try out D=8000. ... noticed high current but onlu 93 corrections (a new low)
  - t3: try out D=6000 ... higher number of corrections 116 vs. 93 in t2

- Best run: 11 out of 11
- Raw test results: [here](https://drive.google.com/drive/folders/1nD5HUg7fXMEKyE6TlY9y8KC3_g1m4dyK)

#### 06-08-2026
- Summary:  robot setup in new environment. most of the effort around getting the camera postion right. 

- Best run: 11 out of 11
- Raw test results: [here](https://drive.google.com/drive/folders/1J09zW2qGBZkC6eC7I8WdvZEpE4VXiENz)

#### 06-04-2026
- Summary:  There were three main changes to the code and environment today. 
 1. The jiggle logic was tweaked to make it happen sooner and ensure that it was not conflicting with the last pid command. In addition, I boosted the rad step to make the jiggle more pronounced. 
 2. the heuristic logic around ball and cup resizing was changed to reduce the number of false negatives. I'm every so often shifting the camera position and lighting. This puts stress on the ball detector code and ML model. The latest changes were to make them more robust.
 3. Some backgrounding lighting was added. I ran somne experiments and found that the model did worse if the light was shining directly on the cup and ball. Indirect lighting was better.

  -t1: Changed position of camera. neutralize last command when jiggle starts and increase rad for jiggle (to 0.05) and reduce the time before the jiggle is kicked off to 1s from 2s:  -p jiggle_start_delay:=1.0 -p jiggle_amplitude :=0.05
  -t2: Added some background light. the light points to the wall next to the robot (vs. shining directly on it....the latter reduced the detection confidence). The results of this test showed that some of the heuristic logic to deal with the ball resizing failed to work well. This could be seen in the ball_detector_oak output:
  ```
  [INFO] [1780609725.940261277] [ball_detector_oak]: Cup  bbox: 174x166px  conf=0.888
[INFO] [1780609726.276870288] [ball_detector_oak]: Ball bbox: 25x27px  conf=0.716
[INFO] [1780609726.943048081] [ball_detector_oak]: Cup  bbox: 174x167px  conf=0.895
[INFO] [1780609727.278684645] [ball_detector_oak]: Ball bbox: 25x28px  conf=0.720
[WARN] [1780609727.861333661] [ball_detector_oak]: Cup  size jump 47% -- rejected (det=192x252px conf=0.804 prev=188x171px)
[WARN] [1780609727.869730031] [ball_detector_oak]: Ball (conf=0.733) found but NO CUP
[INFO] [1780609727.944465241] [ball_detector_oak]: Cup  bbox: 189x179px  conf=0.827
[INFO] [1780609728.037485079] [ball_detector_oak]: [publish] proc=8.9ms  budget=83.3ms  OK
[INFO] [1780609728.281429976] [ball_detector_oak]: Ball bbox: 28x33px  conf=0.747
[WARN] [1780609728.792159683] [ball_detector_oak]: Ball size jump 63% -- rejected
[WARN] [1780609728.794800026] [ball_detector_oak]: No detections
[WARN] [1780609728.861737284] [ball_detector_oak]: Cup  size jump 56% -- rejected (det=280x164px conf=0.533 prev=179x183px)
[WARN] [1780609729.865171246] [ball_detector_oak]: Cup  size jump 56% -- rejected (det=280x163px conf=0.558 prev=179x183px)
[WARN] [1780609729.866666527] [ball_detector_oak]: Ball size jump 64% -- rejected
[WARN] [1780609729.949579924] [ball_detector_oak]: Cup rejected by ROI: cx=0.58 cy=0.25
[WARN] [1780609730.867158314] [ball_detector_oak]: Cup  size jump 56% -- rejected (det=280x164px conf=0.456 prev=179x183px)
[WARN] [1780609730.868813984] [ball_detector_oak]: No detections
[WARN] [1780609730.953893979] [ball_detector_oak]: Ball size jump 58% -- rejected
[WARN] [1780609731.950955862] [ball_detector_oak]: Cup  size jump 56% -- rejected (det=280x164px conf=0.494 prev=179x183px)
[WARN] [1780609732.033131954] [ball_detector_oak]: Ball size jump 63% -- rejected
[WARN] [1780609732.034281304] [ball_detector_oak]: Cup rejected by ROI: cx=0.53 cy=0.23
[WARN] [1780609732.956211676] [ball_detector_oak]: No detections
[WARN] [1780609733.035989130] [ball_detector_oak]: Ball size jump 60% -- rejected
[WARN] [1780609733.038049518] [ball_detector_oak]: Cup  size jump 57% -- rejected (det=280x164px conf=0.517 prev=179x183px)
[INFO] [1780609733.728210463] [ball_detector_oak]: Arm SETTLED — ball/cup size reference reset
[INFO] [1780609733.787434670] [ball_detector_oak]: Cup  bbox: 278x164px  conf=0.574
[WARN] [1780609733.789367949] [ball_detector_oak]: Cup (conf=0.574) found but NO BALL
[INFO] [1780609733.871361412] [ball_detector_oak]: Ball bbox: 20x16px  conf=0.413
[INFO] [1780609733.872748913] [ball_detector_oak]: Warmup (2/10): containment check bypassed

  ```
  -t3: Made the heuristic more robust. However, calls into question the resizing heurstic anyway now that we have a containment heurstic in play (i.e., ball is always within the cup...the ML model doesn't use this fact in its calculations)

- Best run: 11 out of 11
- Raw test results: [here](https://drive.google.com/drive/folders/1Cqwexwd-s7kCWslHpN-VQlZsz4dfavEb)
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

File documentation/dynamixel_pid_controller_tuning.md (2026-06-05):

# Dynamixel PID controller tuning

TBD

In this section we should write up the findings on the needed PID tuning of the dynamixel servos and the accellerated 
current draw and the INA219 current bottleneck (and the work around).
This section will mainly discuss the motivation and outcome that comes from the [servo_config_node.py](../writing_robot_description/writing_robot_description/servo_config_node.py)

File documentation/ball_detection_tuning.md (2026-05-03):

# Ball Detection Tuning
A number of steps were needed to get the ball detection node working properly. This section discusses some of them and includes:
- coordinates 
- training issues: resolution vs. size
- camera exposure time
- FPS and impact on rviz and PID effectiveness
- USB bandwidth bottleneck on Nvidia orin nano
- Camera inference timing

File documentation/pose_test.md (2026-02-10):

# Running the Pose Test utility

This ros2 utility does a number of tests that include:
1. running through a sequence of pre-defined poses
2. perform range of motion tests of defined joints in the robot system
3. measure various properties of the robot in the current pose (servo temperature, current, voltage, etc)
4. validate poses wrt to the bounds defined in the urdf file

## Table of contents
- [Parameters](#parameters)
- [Pose Sequence Example](#pose-sequence-example)
- [Servo Range of motion test example](#servo-range-of-motion-test-example)
- [Example of a validation error](#example-of-a-validation-error)
- [FAQ](#faq)

## Parameters

The parameters are:
| parameter name | default | description |
|---|---|---|
|`poses_file`| |The argument should be the file path to a yaml formatted set of poses. See [example pose sequence yaml file](https://github.com/bueche/ros2_robot_arm/blob/main/writing_robot_description/config/delivery_poses.yaml) for more detail.|
| `program`|| This can have an argument value of calibration, sweep, stress, or default. Each represents a sequence of poses.|
| `servo_test`| False| if true then a servo range-of-motion test is run. Must be accompanied by the `servo_test_joint` parameter (see next).|
| `servo_test_joint`|| Specific joint to test and can have a value of shoulder_pan, shoulder_lift, elbow_flex, elbow_flex, wrist_roll, and pen_holder.|
| `safe_position_first`| `True`| should the arm position itself first in the safe pose?|
| `validate`| `True`| should the program check to ensure that the next pose is safe or not (within the bounds specified in the urdf)|
| `telemetry`| `False`| should the servo stats be sampled after each pose? the stats include temperature, current, voltage, etc.|
| `delay`|`2.0`| The time in seconds to delay between each pose.|
| `movement_time`| `2.0`| how much time should the arm have to complete the transition from the current pose to the next pose.|
| `urdf_file`| |Load URDF from file. (TODO: should have a default file to load)|
| `power_monitoring`| |Determines whether or not the power monitoring will take place during poses. See [power_monitor_node](./writing_robot_control/writing_robot_comtrol/power_monitor.py).

## Pose Sequence Example
An example run through a sequence of poses is as follows. In this test the robot will go through a short simulated package handling scenario. Each pose transition is to occur within one second and there will be a one second pause between each pose. The software will also validate the that each pose is allowed by the URDF definition and stop if it does not. 

The particular example illustrated is defined by [this pose sequence](../src/writing_robot_description/config/delivery_poses.yaml) and is illustrated in the story board below (which was an rviz2 reproduction of the actual physical robot movements). 

<p align="center">
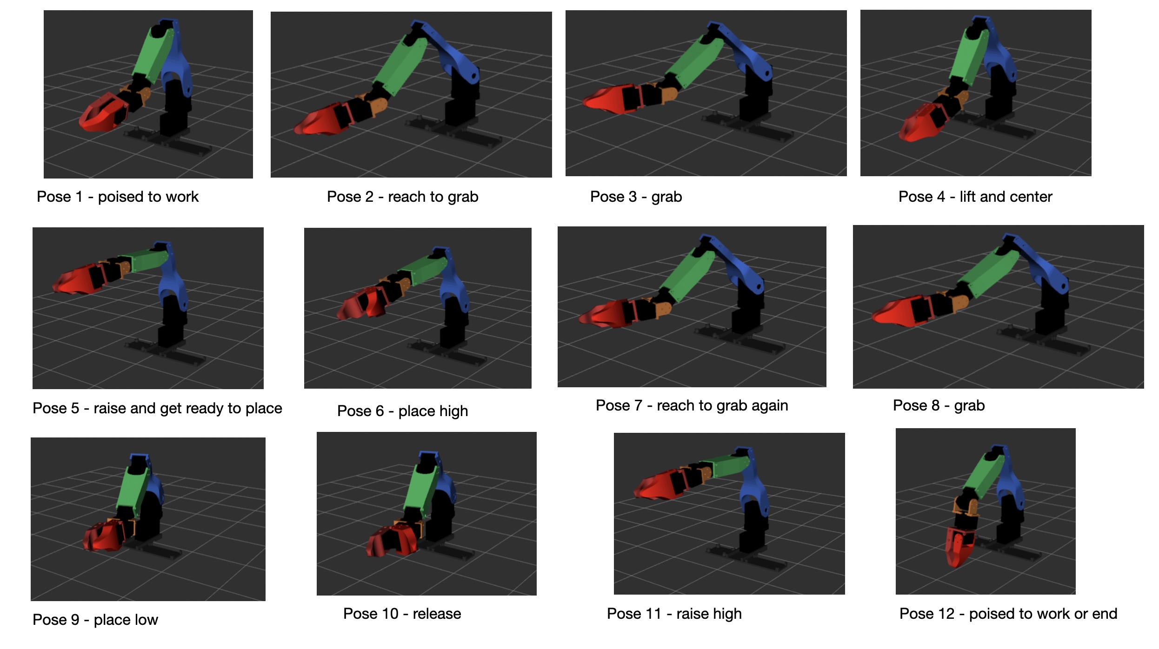
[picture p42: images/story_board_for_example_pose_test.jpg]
story board for example pose test
  
</p>

Ouptut from the Pose Test utility is given below.

```bash
ubuntu@bueche-rpi5:~/robot_ws$ ros2 run writing_robot_control pose_test --ros-args -p poses_file:=src/writing_robot_description/config/delivery_poses.yaml -p validate:=true -p telemetry:=true -p urdf_file:=src/writing_robot_description/urdf/koch_v11_arm_real.urdf -p power_monitoring:=true -p delay:=2.0
POWER_MONITORING_AVAILABLEF: True
[INFO] [1770595611.286299681] [pose_test_node]: Loading URDF limits...
[INFO] [1770595611.288279858] [pose_test_node]: ✓ Loaded limits for 6 joints
[INFO] [1770595611.288832713] [pose_test_node]: Initializing telemetry...
[INFO] [1770595611.294631206] [pose_test_node]: ✓ Telemetry initialized (dual-topic mode)
[INFO] [1770595611.295322302] [pose_test_node]:   - Subscribing to /joint_states
[INFO] [1770595611.295852787] [pose_test_node]:   - Subscribing to /dxl_state
[INFO] [1770595611.296357660] [pose_test_node]:   - XL430 servos (IDs 1,2): Load only
[INFO] [1770595611.296849459] [pose_test_node]:   - XL330 servos (IDs 3-6): Current + Load
[INFO] [1770595612.885336866] [pose_test_node]: ✓ Telemetry active
[INFO] [1770595612.891349954] [pose_test_node]: ✓ Power monitoring enabled
[INFO] [1770595612.892337792] [pose_test_node]: ============================================================
[INFO] [1770595612.892954888] [pose_test_node]: POSE TEST NODE INITIALIZED
[INFO] [1770595612.893496724] [pose_test_node]: ============================================================
[INFO] [1770595612.894010523] [pose_test_node]: Joints: 6
[INFO] [1770595612.894527600] [pose_test_node]: Validation: True
[INFO] [1770595612.895140048] [pose_test_node]: Telemetry: True
[INFO] [1770595612.895788014] [pose_test_node]: Power Monitoring: Enabled
[INFO] [1770595612.896471610] [pose_test_node]: Movement time: 2.0s
[INFO] [1770595612.897053669] [pose_test_node]: Delay between poses: 2.0s
[INFO] [1770595612.897580061] [pose_test_node]: ============================================================
[INFO] [1770595612.898085119] [pose_test_node]: Waiting for joint trajectory controller...
[INFO] [1770595614.918960495] [pose_test_node]: ✓ Loaded 11 poses from src/writing_robot_description/config/delivery_poses.yaml
[INFO] [1770595614.919536684] [pose_test_node]: 
============================================================
[INFO] [1770595614.920086372] [pose_test_node]: POSE SEQUENCE TEST
[INFO] [1770595614.920945302] [pose_test_node]: ============================================================
[INFO] [1770595614.921602917] [pose_test_node]: Total poses: 11
[INFO] [1770595614.922170049] [pose_test_node]: Validation: True
[INFO] [1770595614.922684700] [pose_test_node]: Telemetry: True
[INFO] [1770595614.923166258] [pose_test_node]: ============================================================
[INFO] [1770595614.923662002] [pose_test_node]: 
[1/11] pose 1 - poised to work
[INFO] [1770595614.924154041] [pose_test_node]:   ✓ shoulder_pan: 1.558 rad (within [0.540, 2.044])
[INFO] [1770595614.924652303] [pose_test_node]:   ✓ shoulder_lift: 2.879 rad (within [2.200, 2.886])
[INFO] [1770595614.925128361] [pose_test_node]:   ✓ elbow_flex: 2.124 rad (within [0.726, 2.250])
[INFO] [1770595614.925638438] [pose_test_node]:   ✓ wrist_flex: 2.279 rad (within [0.297, 2.700])
[INFO] [1770595614.926148607] [pose_test_node]:   ✓ wrist_roll: 1.182 rad (within [-1.448, 1.900])
[INFO] [1770595614.926671777] [pose_test_node]:   ✓ pen_holder: 1.590 rad (within [0.190, 1.600])
[INFO] [1770595614.927827338] [pose_test_node]: → Sent: pose 1 - poised to work
[INFO] [1770595618.934589703] [pose_test_node]:   📊 Joint States:
[INFO] [1770595618.935407226] [pose_test_node]:   📊 shoulder_pan    [XL430] Pos:  1.557rad Load:  0.00% Volt:12.1V Temp: 32.0°C
[INFO] [1770595618.936180933] [pose_test_node]:   📊 shoulder_lift   [XL430] Pos:  2.839rad Load: 14.00% Volt:12.1V Temp: 34.0°C
[INFO] [1770595618.937008160] [pose_test_node]:   📊 elbow_flex      [XL330] Pos:  2.303rad Curr: -109mA Volt: 5.5V Temp: 21.0°C
[INFO] [1770595618.937838905] [pose_test_node]:   📊 wrist_flex      [XL330] Pos:  2.276rad Curr:   13mA Volt: 5.4V Temp: 21.0°C
[INFO] [1770595618.938645446] [pose_test_node]:   📊 wrist_roll      [XL330] Pos:  1.186rad Curr:  -12mA Volt: 5.5V Temp: 22.0°C
[INFO] [1770595618.939474062] [pose_test_node]:   📊 pen_holder      [XL330] Pos:  1.621rad Curr:  -21mA Volt: 5.4V Temp: 22.0°C
[INFO] [1770595618.940354344] [pose_test_node]:   ⚡ Power Analysis for "pose 1 - poised to work":
[INFO] [1770595618.941070959] [pose_test_node]:      Peak 5V current (INA219):    0.199A
[INFO] [1770595618.941883204] [pose_test_node]:      Peak motor sum (XL330s):     0.162A
[INFO] [1770595618.942663431] [pose_test_node]:      5V voltage: 5.66V (min) / 5.78V (max)
[INFO] [1770595618.943420453] [pose_test_node]:      Peak 12V current:            0.147A
[INFO] [1770595618.944070382] [pose_test_node]:      Peak total power:            2.70W
[INFO] [1770595618.944706071] [pose_test_node]:      Holding current comparison:
[INFO] [1770595618.945295500] [pose_test_node]:        Supply current (INA219):     0.197A
[INFO] [1770595618.945858670] [pose_test_node]:        Motor current sum (XL330s):  0.155A
[INFO] [1770595618.946427932] [pose_test_node]:        ✓ Supply within 50mA of  motor sum
[INFO] [1770595618.947019361] [pose_test_node]: 
[2/11] pose 2 - reach to grab
[INFO] [1770595618.947647864] [pose_test_node]:   ✓ shoulder_pan: 1.283 rad (within [0.540, 2.044])
[INFO] [1770595618.948243219] [pose_test_node]:   ✓ shoulder_lift: 2.314 rad (within [2.200, 2.886])
[INFO] [1770595618.948847352] [pose_test_node]:   ✓ elbow_flex: 1.320 rad (within [0.726, 2.250])
[INFO] [1770595618.949454281] [pose_test_node]:   ✓ wrist_flex: 2.279 rad (within [0.297, 2.700])
[INFO] [1770595618.949942839] [pose_test_node]:   ✓ wrist_roll: 1.871 rad (within [-1.448, 1.900])
[INFO] [1770595618.950446083] [pose_test_node]:   ✓ pen_holder: 0.982 rad (within [0.190, 1.600])
[INFO] [1770595618.951630145] [pose_test_node]: → Sent: pose 2 - reach to grab
[INFO] [1770595622.959307569] [pose_test_node]:   📊 Joint States:
[INFO] [1770595622.960186963] [pose_test_node]:   📊 shoulder_pan    [XL430] Pos:  1.282rad Load: -0.20% Volt:12.1V Temp: 32.0°C
[INFO] [1770595622.961265228] [pose_test_node]:   📊 shoulder_lift   [XL430] Pos:  2.293rad Load:  7.20% Volt:12.1V Temp: 34.0°C
[INFO] [1770595622.962400956] [pose_test_node]:   📊 elbow_flex      [XL330] Pos:  1.497rad Curr: -107mA Volt: 5.5V Temp: 21.0°C
[INFO] [1770595622.963309868] [pose_test_node]:   📊 wrist_flex      [XL330] Pos:  2.275rad Curr:   14mA Volt: 5.4V Temp: 21.0°C
[INFO] [1770595622.964102521] [pose_test_node]:   📊 wrist_roll      [XL330] Pos:  1.865rad Curr:   12mA Volt: 5.4V Temp: 21.0°C
[INFO] [1770595622.964913155] [pose_test_node]:   📊 pen_holder      [XL330] Pos:  1.031rad Curr:  -26mA Volt: 5.4V Temp: 22.0°C
[INFO] [1770595622.965831974] [pose_test_node]:   ⚡ Power Analysis for "pose 2 - reach to grab":
[INFO] [1770595622.966556515] [pose_test_node]:      Peak 5V current (INA219):    0.202A
[INFO] [1770595622.967254760] [pose_test_node]:      Peak motor sum (XL330s):     0.182A
[INFO] [1770595622.967983486] [pose_test_node]:      5V voltage: 5.66V (min) / 5.77V (max)
[INFO] [1770595622.968709193] [pose_test_node]:      Peak 12V current:            0.123A
[INFO] [1770595622.969415197] [pose_test_node]:      Peak total power:            2.63W
[INFO] [1770595622.970100089] [pose_test_node]:      Holding current comparison:
[INFO] [1770595622.970903131] [pose_test_node]:        Supply current (INA219):     0.200A
[INFO] [1770595622.971839136] [pose_test_node]:        Motor current sum (XL330s):  0.159A
[INFO] [1770595622.972448380] [pose_test_node]:        ✓ Supply within 50mA of  motor sum
[INFO] [1770595622.972988364] [pose_test_node]: 
[3/11] pose 3 - grab
[INFO] [1770595622.973529274] [pose_test_node]:   ✓ shoulder_pan: 1.329 rad (within [0.540, 2.044])
[INFO] [1770595622.974001740] [pose_test_node]:   ✓ shoulder_lift: 2.322 rad (within [2.200, 2.886])
[INFO] [1770595622.974470909] [pose_test_node]:   ✓ elbow_flex: 1.005 rad (within [0.726, 2.250])
[INFO] [1770595622.974955411] [pose_test_node]:   ✓ wrist_flex: 2.279 rad (within [0.297, 2.700])
[INFO] [1770595622.975449655] [pose_test_node]:   ✓ wrist_roll: 1.766 rad (within [-1.448, 1.900])
[INFO] [1770595622.975919916] [pose_test_node]:   ✓ pen_holder: 1.501 rad (within [0.190, 1.600])
[INFO] [1770595622.976991385] [pose_test_node]: → Sent: pose 3 - grab
[INFO] [1770595626.982988653] [pose_test_node]:   📊 Joint States:
[INFO] [1770595626.983824509] [pose_test_node]:   📊 shoulder_pan    [XL430] Pos:  1.321rad Load:  3.30% Volt:12.1V Temp: 32.0°C
[INFO] [1770595626.984632624] [pose_test_node]:   📊 shoulder_lift   [XL430] Pos:  2.279rad Load: 15.80% Volt:12.1V Temp: 34.0°C
[INFO] [1770595626.985436036] [pose_test_node]:   📊 elbow_flex      [XL330] Pos:  1.204rad Curr: -127mA Volt: 5.4V Temp: 21.0°C
[INFO] [1770595626.986250614] [pose_test_node]:   📊 wrist_flex      [XL330] Pos:  2.275rad Curr:   14mA Volt: 5.4V Temp: 21.0°C
[INFO] [1770595626.987051156] [pose_test_node]:   📊 wrist_roll      [XL330] Pos:  1.766rad Curr:    0mA Volt: 5.5V Temp: 21.0°C
[INFO] [1770595626.987946790] [pose_test_node]:   📊 pen_holder      [XL330] Pos:  1.470rad Curr:   19mA Volt: 5.5V Temp: 22.0°C
[INFO] [1770595626.988853813] [pose_test_node]:   ⚡ Power Analysis for "pose 3 - grab":
[INFO] [1770595626.989580132] [pose_test_node]:      Peak 5V current (INA219):    0.296A
[INFO] [1770595626.990292654] [pose_test_node]:      Peak motor sum (XL330s):     0.308A
[INFO] [1770595626.991077270] [pose_test_node]:      5V voltage: 5.57V (min) / 5.77V (max)
[INFO] [1770595626.991991034] [pose_test_node]:      Peak 12V current:            0.147A
[INFO] [1770595626.992792001] [pose_test_node]:      Peak total power:            3.29W
[INFO] [1770595626.993524486] [pose_test_node]:      Holding current comparison:
[INFO] [1770595626.994062063] [pose_test_node]:        Supply current (INA219):     0.207A
[INFO] [1770595626.994644640] [pose_test_node]:        Motor current sum (XL330s):  0.160A
[INFO] [1770595626.995276218] [pose_test_node]:        ✓ Supply within 50mA of  motor sum
[INFO] [1770595626.995846461] [pose_test_node]: 
[4/11] pose 4 - lift and center
[INFO] [1770595626.996459150] [pose_test_node]:   ✓ shoulder_pan: 1.576 rad (within [0.540, 2.044])
[INFO] [1770595626.997025116] [pose_test_node]:   ✓ shoulder_lift: 2.575 rad (within [2.200, 2.886])
[INFO] [1770595626.997575841] [pose_test_node]:   ✓ elbow_flex: 1.898 rad (within [0.726, 2.250])
[INFO] [1770595626.998075232] [pose_test_node]:   ✓ wrist_flex: 2.279 rad (within [0.297, 2.700])
[INFO] [1770595626.998567494] [pose_test_node]:   ✓ wrist_roll: 1.766 rad (within [-1.448, 1.900])
[INFO] [1770595626.999073015] [pose_test_node]:   ✓ pen_holder: 1.521 rad (within [0.190, 1.600])
[INFO] [1770595627.000152577] [pose_test_node]: → Sent: pose 4 - lift and center
[INFO] [1770595631.006279604] [pose_test_node]:   📊 Joint States:
[INFO] [1770595631.007101461] [pose_test_node]:   📊 shoulder_pan    [XL430] Pos:  1.571rad Load:  1.60% Volt:12.3V Temp: 32.0°C
[INFO] [1770595631.007950150] [pose_test_node]:   📊 shoulder_lift   [XL430] Pos:  2.528rad Load: 17.10% Volt:12.1V Temp: 35.0°C
[INFO] [1770595631.008715099] [pose_test_node]:   📊 elbow_flex      [XL330] Pos:  1.931rad Curr:  -15mA Volt: 5.7V Temp: 21.0°C
[INFO] [1770595631.009499862] [pose_test_node]:   📊 wrist_flex      [XL330] Pos:  2.275rad Curr:   14mA Volt: 5.6V Temp: 21.0°C
[INFO] [1770595631.010273662] [pose_test_node]:   📊 wrist_roll      [XL330] Pos:  1.766rad Curr:    0mA Volt: 5.7V Temp: 21.0°C
[INFO] [1770595631.011112445] [pose_test_node]:   📊 pen_holder      [XL330] Pos:  1.496rad Curr:   19mA Volt: 5.6V Temp: 22.0°C
[INFO] [1770595631.012230488] [pose_test_node]:   ⚡ Power Analysis for "pose 4 - lift and center":
[INFO] [1770595631.013348512] [pose_test_node]:      Peak 5V current (INA219):    0.207A
[INFO] [1770595631.014014682] [pose_test_node]:      Peak motor sum (XL330s):     0.170A
[INFO] [1770595631.014584630] [pose_test_node]:      5V voltage: 5.66V (min) / 5.78V (max)
[INFO] [1770595631.015131188] [pose_test_node]:      Peak 12V current:            0.226A
[INFO] [1770595631.015674673] [pose_test_node]:      Peak total power:            3.34W
[INFO] [1770595631.016219398] [pose_test_node]:      Holding current comparison:
[INFO] [1770595631.016789734] [pose_test_node]:        Supply current (INA219):     0.099A
[INFO] [1770595631.017449960] [pose_test_node]:        Motor current sum (XL330s):  0.048A
[WARN] [1770595631.018139148] [pose_test_node]:        ⚠ Supply higher than motor sum by 0.051A!
[INFO] [1770595631.018772189] [pose_test_node]: 
[5/11] pose 5 - raise and get ready to place
[INFO] [1770595631.019402896] [pose_test_node]:   ✓ shoulder_pan: 1.596 rad (within [0.540, 2.044])
[INFO] [1770595631.020014584] [pose_test_node]:   ✓ shoulder_lift: 2.795 rad (within [2.200, 2.886])
[INFO] [1770595631.020972386] [pose_test_node]:   ✓ elbow_flex: 0.970 rad (within [0.726, 2.250])
[INFO] [1770595631.021680371] [pose_test_node]:   ✓ wrist_flex: 1.473 rad (within [0.297, 2.700])
[INFO] [1770595631.022307226] [pose_test_node]:   ✓ wrist_roll: 1.762 rad (within [-1.448, 1.900])
[INFO] [1770595631.022878192] [pose_test_node]:   ✓ pen_holder: 1.521 rad (within [0.190, 1.600])
[INFO] [1770595631.024021291] [pose_test_node]: → Sent: pose 5 - raise and get ready to place
[INFO] [1770595635.029673131] [pose_test_node]:   📊 Joint States:
[INFO] [1770595635.030496857] [pose_test_node]:   📊 shoulder_pan    [XL430] Pos:  1.585rad Load:  4.40% Volt:12.1V Temp: 32.0°C
[INFO] [1770595635.031631659] [pose_test_node]:   📊 shoulder_lift   [XL430] Pos:  2.738rad Load: 19.50% Volt:12.1V Temp: 35.0°C
[INFO] [1770595635.032539072] [pose_test_node]:   📊 elbow_flex      [XL330] Pos:  1.197rad Curr: -157mA Volt: 5.4V Temp: 21.0°C
[INFO] [1770595635.033470965] [pose_test_node]:   📊 wrist_flex      [XL330] Pos:  1.465rad Curr:   14mA Volt: 5.4V Temp: 21.0°C
[INFO] [1770595635.034200914] [pose_test_node]:   📊 wrist_roll      [XL330] Pos:  1.761rad Curr:    0mA Volt: 5.4V Temp: 21.0°C
[INFO] [1770595635.034980973] [pose_test_node]:   📊 pen_holder      [XL330] Pos:  1.496rad Curr:   18mA Volt: 5.4V Temp: 22.0°C
[INFO] [1770595635.035845441] [pose_test_node]:   ⚡ Power Analysis for "pose 5 - raise and get ready to place":
[INFO] [1770595635.036509426] [pose_test_node]:      Peak 5V current (INA219):    0.263A
[INFO] [1770595635.037135207] [pose_test_node]:      Peak motor sum (XL330s):     0.242A
[INFO] [1770595635.037770544] [pose_test_node]:      5V voltage: 5.60V (min) / 5.77V (max)
[INFO] [1770595635.038420121] [pose_test_node]:      Peak 12V current:            0.204A
[INFO] [1770595635.039040439] [pose_test_node]:      Peak total power:            3.80W
[INFO] [1770595635.039636683] [pose_test_node]:      Holding current comparison:
[INFO] [1770595635.040205501] [pose_test_node]:        Supply current (INA219):     0.236A
[INFO] [1770595635.040792134] [pose_test_node]:        Motor current sum (XL330s):  0.189A
[INFO] [1770595635.041546582] [pose_test_node]:        ✓ Supply within 50mA of  motor sum
[INFO] [1770595635.042283327] [pose_test_node]: 
[6/11] pose 6 - place high
[INFO] [1770595635.042983497] [pose_test_node]:   ✓ shoulder_pan: 1.598 rad (within [0.540, 2.044])
[INFO] [1770595635.043636593] [pose_test_node]:   ✓ shoulder_lift: 2.655 rad (within [2.200, 2.886])
[INFO] [1770595635.044146226] [pose_test_node]:   ✓ elbow_flex: 0.806 rad (within [0.726, 2.250])
[INFO] [1770595635.044632858] [pose_test_node]:   ✓ wrist_flex: 1.473 rad (within [0.297, 2.700])
[INFO] [1770595635.045090619] [pose_test_node]:   ✓ wrist_roll: 1.762 rad (within [-1.448, 1.900])
[INFO] [1770595635.045583918] [pose_test_node]:   ✓ pen_holder: 0.655 rad (within [0.190, 1.600])
[INFO] [1770595635.046660480] [pose_test_node]: → Sent: pose 6 - place high
[INFO] [1770595639.054135903] [pose_test_node]:   📊 Joint States:
[INFO] [1770595639.054977241] [pose_test_node]:   📊 shoulder_pan    [XL430] Pos:  1.585rad Load:  5.00% Volt:12.1V Temp: 32.0°C
[INFO] [1770595639.055810875] [pose_test_node]:   📊 shoulder_lift   [XL430] Pos:  2.648rad Load:  2.20% Volt:12.1V Temp: 35.0°C
[INFO] [1770595639.057763997] [pose_test_node]:   📊 elbow_flex      [XL330] Pos:  1.051rad Curr: -176mA Volt: 5.3V Temp: 22.0°C
[INFO] [1770595639.059192430] [pose_test_node]:   📊 wrist_flex      [XL330] Pos:  1.463rad Curr:   14mA Volt: 5.4V Temp: 21.0°C
[INFO] [1770595639.060223361] [pose_test_node]:   📊 wrist_roll      [XL330] Pos:  1.759rad Curr:   11mA Volt: 5.4V Temp: 21.0°C
[INFO] [1770595639.061494553] [pose_test_node]:   📊 pen_holder      [XL330] Pos:  0.709rad Curr:  -28mA Volt: 5.3V Temp: 22.0°C
[INFO] [1770595639.062503299] [pose_test_node]:   ⚡ Power Analysis for "pose 6 - place high":
[INFO] [1770595639.063174507] [pose_test_node]:      Peak 5V current (INA219):    0.439A
[INFO] [1770595639.063763880] [pose_test_node]:      Peak motor sum (XL330s):     0.428A
[INFO] [1770595639.064322772] [pose_test_node]:      5V voltage: 5.43V (min) / 5.78V (max)
[INFO] [1770595639.064838441] [pose_test_node]:      Peak 12V current:            0.121A
[INFO] [1770595639.065348018] [pose_test_node]:      Peak total power:            3.79W
[INFO] [1770595639.065854076] [pose_test_node]:      Holding current comparison:
[INFO] [1770595639.066389135] [pose_test_node]:        Supply current (INA219):     0.269A
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

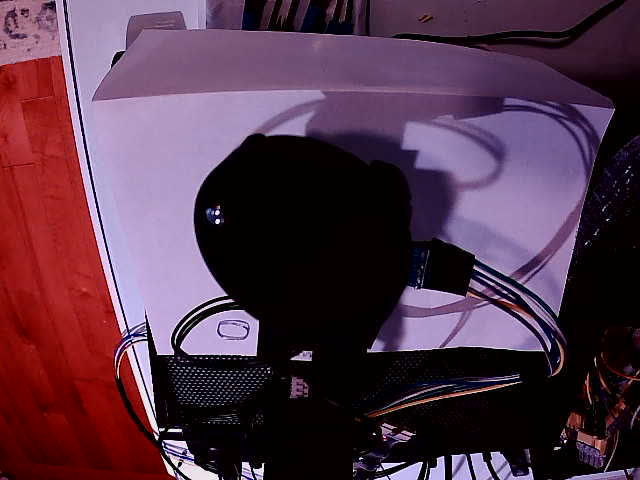
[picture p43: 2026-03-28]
balance/tests/ball_test_images/pose_tilt_right_2.jpg

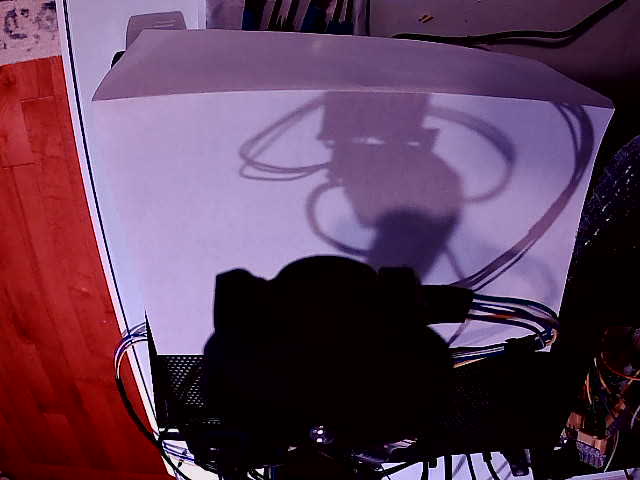
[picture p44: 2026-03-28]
balance/tests/ball_test_images/pose_tilt_back_2.jpg

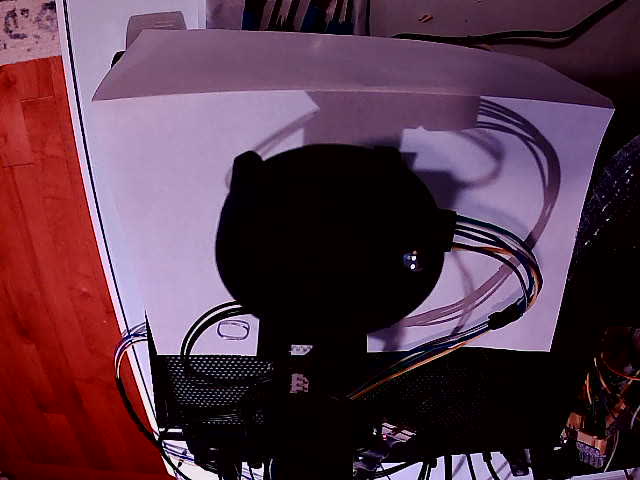
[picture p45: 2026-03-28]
balance/tests/ball_test_images/pose_centre_2.jpg

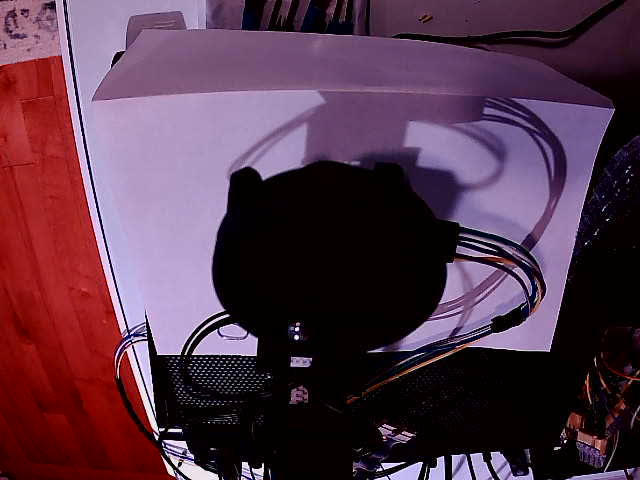
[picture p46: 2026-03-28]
balance/tests/ball_test_images/pose_centre_3.jpg

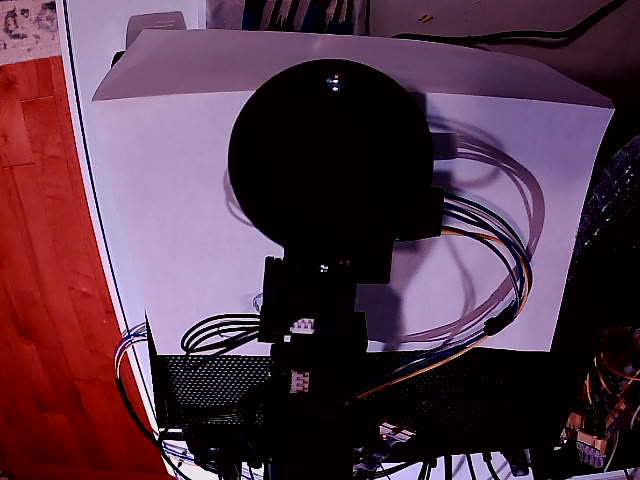
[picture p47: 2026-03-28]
balance/tests/ball_test_images/pose_tilt_forward.jpg

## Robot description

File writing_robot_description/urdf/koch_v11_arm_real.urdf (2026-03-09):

<?xml version="1.0"?>
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
<robot name="koch_v11_writing_arm">


  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
  <link name="base_link">
    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
   <inertial>
      <origin xyz="0.002157 0.002598 0.014585" rpy="0 0 0"/>
      <mass value="0.089861"/>
      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
    </inertial>
  </link>

  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
  <joint name="shoulder_pan" type="revolute">
    <parent link="base_link"/>
    <child link="shoulder_link"/>
    <origin xyz="0.001000 0.017000 0.042000" rpy="0.000000 0.000000 0.000000"/>
    <axis xyz="0.000000 0.000000 1.000000"/>
    <limit lower="2.044" upper="0.540" effort="2.0" velocity="3.14"/>
  </joint>

  <link name="shoulder_link">
    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
   <inertial>
     <origin xyz="-0.000000 0.000000 0.037821" rpy="0 0 0"/>
     <mass value="0.061576"/>
     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
   </inertial>
   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
  </link>

  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
  <joint name="shoulder_lift" type="revolute">
    <parent link="shoulder_link"/>
    <child link="upper_arm_link"/>
    <origin xyz="-0.001000 0.000000 0.038000" rpy="3.14159 1.570796 0.000000"/>
    <axis xyz="0.000000 -1.000000 0.000000"/>
    <limit lower="2.8857" upper="2.2000" effort="2.0" velocity="3.14"/>
  </joint>

  <link name="upper_arm_link">
    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
   <inertial>
      <origin xyz="0.050128 -0.023836 0.130136" rpy="0 0 0"/>
      <mass value="0.071602"/>
      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
   </inertial>
   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
  </link>

  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
  <joint name="elbow_flex" type="revolute">
    <parent link="upper_arm_link"/>
    <child link="forearm_link"/>
    <origin xyz="0.109000 0.000000 -0.013000" rpy="3.14159 0.000000 0.000000"/>
    <axis xyz="0.000000 -1.000000 0.000000"/>
    <limit lower="0.726" upper="2.250" effort="1.5" velocity="3.14"/>
  </joint>

  <link name="forearm_link">
    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
    <inertial>
      <origin xyz="0.100026 0.011432 0.002300" rpy="0 0 0"/>
      <mass value="0.088473"/>
      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
    </inertial>
    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
  </link>

  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
  <joint name="wrist_flex" type="revolute">
    <parent link="forearm_link"/>
    <child link="wrist_link"/>
    <origin xyz="0.101000 -0.001000 0.003000" rpy="0.000000 0.000000 0.000000"/>
    <axis xyz="0.000000 1.000000 0.000000"/>
    <limit lower="2.70" upper="0.297" effort="1.5" velocity="3.14"/>
  </joint>

  <link name="wrist_link">
    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
    <inertial>
      <origin xyz="0.039162 0.041751 0.050877" rpy="0 0 0"/>
      <mass value="0.034634"/>
      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
    </inertial>
    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
  </link>

  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
  <joint name="wrist_roll" type="revolute">
    <parent link="wrist_link"/>
    <child link="hand_link"/>
    <origin xyz="-0.001000 0.001000 0.043000" rpy="0.000000 0.000000 -1.570796"/>
    <axis xyz="0.000000 0.000000 1.000000"/>
    <limit lower="1.900" upper="-1.448" effort="1.0" velocity="3.14"/>
  </joint>

  <link name="hand_link">
    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

    <inertial>
      <origin xyz="0.005155 -0.026264 0.024550" rpy="0 0 0"/>
      <mass value="0.045639"/>
      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
    </inertial>
    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
  </link>

  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
  <joint name="pen_holder" type="revolute">
    <parent link="hand_link"/>
    <child link="pen_link"/>
    <origin xyz="0.000000 -0.007000 0.016000" rpy="0.785398 0.000000 0.000000"/>
    <axis xyz="-1.000000 0.000000 0.000000"/>
    <limit lower="1.60" upper="0.19" effort="0.5" velocity="1.57"/>
  </joint>

  <link name="pen_link">
    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
    <inertial>
      <origin xyz="-0.251709 0.176376 0.042951" rpy="0 0 0"/>
      <mass value="0.015925"/>
      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
    </inertial>
    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
  </link>

  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
  <ros2_control name="koch_v11_system" type="system">
	    
    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
    <hardware>
        <plugin>dynamixel_hardware_interface/DynamixelHardware</plugin>
	<param name="usb_port">/dev/ttyOpenRB</param>
	<param name="port_name">/dev/ttyOpenRB</param>
	<param name="baud_rate">1000000</param>
        <param name="number_of_joints">6</param>
	<param name="number_of_transmissions">6</param> 
	<param name="transmission_to_joint_matrix">1,0,0,0,0,0,0,1,0,0,0,0,0,0,1,0,0,0,0,0,0,1,0,0,0,0,0,0,1,0,0,0,0,0,0,1</param>
	<param name="joint_to_transmission_matrix">1,0,0,0,0,0,0,1,0,0,0,0,0,0,1,0,0,0,0,0,0,1,0,0,0,0,0,0,1,0,0,0,0,0,0,1</param>
	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
	<param name="dynamixel_model_folder">/param/dxl_model</param>
	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
	<param name="protocol_version">2.0</param>
    </hardware>
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

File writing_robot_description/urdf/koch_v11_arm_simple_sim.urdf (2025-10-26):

<?xml version="1.0"?>
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
<robot name="koch_v11_writing_arm">

  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
  <link name="base_link">
    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
    <inertial>
      <mass value="0.5"/>
      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
    </inertial>
  </link>

  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
  <joint name="shoulder_pan" type="revolute">
    <parent link="base_link"/>
    <child link="shoulder_link"/>
    <origin xyz="0 0 0.02" rpy="0 0 0"/>
    <axis xyz="0 0 1"/>
    <limit lower="-3.14159" upper="3.14159" effort="2.0" velocity="3.14"/>
  </joint>

  <link name="shoulder_link">
    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
    <inertial>
      <mass value="0.3"/>
      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
    </inertial>
  </link>

  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
  <joint name="shoulder_lift" type="revolute">
    <parent link="shoulder_link"/>
    <child link="upper_arm_link"/>
    <origin xyz="0 0 0.04" rpy="0 0 0"/>
    <axis xyz="0 1 0"/>
    <limit lower="-2.0" upper="2.0" effort="2.0" velocity="3.14"/>
  </joint>

  <link name="upper_arm_link">
    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
    <inertial>
      <mass value="0.2"/>
      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
    </inertial>
  </link>

  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
  <joint name="elbow_flex" type="revolute">
    <parent link="upper_arm_link"/>
    <child link="forearm_link"/>
    <origin xyz="0.20 0 0" rpy="0 0 0"/>
    <axis xyz="0 1 0"/>
    <limit lower="-2.5" upper="2.5" effort="1.5" velocity="3.14"/>
  </joint>

  <link name="forearm_link">
    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
    <inertial>
      <mass value="0.15"/>
      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
    </inertial>
  </link>

  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
  <joint name="wrist_flex" type="revolute">
    <parent link="forearm_link"/>
    <child link="wrist_link"/>
    <origin xyz="0.16 0 0" rpy="0 0 0"/>
    <axis xyz="0 1 0"/>
    <limit lower="-2.0" upper="2.0" effort="1.5" velocity="3.14"/>
  </joint>

  <link name="wrist_link">
    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
    <inertial>
      <mass value="0.1"/>
      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
    </inertial>
  </link>

  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
  <joint name="wrist_roll" type="revolute">
    <parent link="wrist_link"/>
    <child link="hand_link"/>
    <origin xyz="0.05 0 0" rpy="0 0 0"/>
    <axis xyz="1 0 0"/>
    <limit lower="-3.14159" upper="3.14159" effort="1.0" velocity="3.14"/>
  </joint>

  <link name="hand_link">
    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
    <inertial>
      <mass value="0.08"/>
      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
    </inertial>
  </link>

  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
  <joint name="pen_holder" type="revolute">
    <parent link="hand_link"/>
    <child link="pen_link"/>
    <origin xyz="0.10 0 0" rpy="0 0 0"/>
    <axis xyz="0 1 0"/>
    <limit lower="-0.5" upper="0.5" effort="0.5" velocity="1.57"/>
  </joint>

  <link name="pen_link">
    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
    <inertial>
      <mass value="0.02"/>
      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
    </inertial>
  </link>

  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
  <joint name="pen_tip_joint" type="fixed">
    <parent link="pen_link"/>
    <child link="pen_tip"/>
    <origin xyz="0.05 0 0" rpy="0 0 0"/>
  </joint>

  <link name="pen_tip">
    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
  </link>

  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
  <ros2_control name="koch_v11_system" type="system">
    
    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
    <hardware>
      <plugin>mock_components/GenericSystem</plugin>
    </hardware>
    
    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
    <joint name="shoulder_pan">
      <command_interface name="position">
        <param name="min">-3.14159</param>
        <param name="max">3.14159</param>
      </command_interface>
      <state_interface name="position">
        <param name="initial_value">0.0</param>
      </state_interface>
      <state_interface name="position"/>
      <state_interface name="velocity"/>
    </joint>
    
    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
    <joint name="shoulder_lift">
      <command_interface name="position">
        <param name="min">-2.0</param>
        <param name="max">2.0</param>
      </command_interface>
      <state_interface name="position">
        <param name="initial_value">0.0</param>
      </state_interface>
      <state_interface name="position"/>
      <state_interface name="velocity"/>
    </joint>
    
    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
    <joint name="elbow_flex">
      <command_interface name="position">
        <param name="min">-2.5</param>
        <param name="max">2.5</param>
      </command_interface>
      <state_interface name="position">
        <param name="initial_value">-1.57</param>
      </state_interface>
      <state_interface name="position"/>
      <state_interface name="velocity"/>
    </joint>
    
    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
    <joint name="wrist_flex">
      <command_interface name="position">
        <param name="min">-2.0</param>
        <param name="max">2.0</param>
      </command_interface>
      <state_interface name="position">
        <param name="initial_value">1.57</param>
      </state_interface>
      <state_interface name="position"/>
      <state_interface name="velocity"/>
    </joint>
    
    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
    <joint name="wrist_roll">
      <command_interface name="position">
        <param name="min">-3.14159</param>
        <param name="max">3.14159</param>
      </command_interface>
      <state_interface name="position">
        <param name="initial_value">0.0</param>
      </state_interface>
      <state_interface name="position"/>
      <state_interface name="velocity"/>
    </joint>
    
    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
    <joint name="pen_holder">
      <command_interface name="position">
        <param name="min">-0.5</param>
        <param name="max">0.5</param>
      </command_interface>
      <state_interface name="position">
        <param name="initial_value">0.0</param>
      </state_interface>
      <state_interface name="position"/>
      <state_interface name="velocity"/>
    </joint>
    
  </ros2_control>

</robot>

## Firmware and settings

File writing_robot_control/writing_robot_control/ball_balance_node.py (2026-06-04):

#!/usr/bin/env python3
"""
ball_balance_node.py — Combined camera + IMU ball balancing controller
======================================================================

Replaces imu_balance_node for ball balancing. Uses camera ball position
as the primary error signal and IMU tilt as a derivative/feedforward signal.

Architecture:
  /ball/position      (geometry_msgs/Point)    — camera: where ball IS
  /imu/balance_error      (geometry_msgs/Vector3) — IMU: cup tilt angles (pitch, roll) rad
  /balance/cmd_delta      (geometry_msgs/Vector3) — wrist: commanded flex/roll delta per CORR
  /balance/achieved_delta (geometry_msgs/Vector3) — wrist: actually achieved flex/roll delta
  /imu/raw            (sensor_msgs/Imu)         — IMU: angular_velocity.x=roll_rate,
                                                   angular_velocity.y=pitch_rate (rad/s)
                                                   NOTE: x=roll, y=pitch — opposite to
                                                   ROS REP-103. See _imu_raw_cb.
  /joint_states       (sensor_msgs/JointState) — current joint positions
  /arm_state          (std_msgs/String)         — MOVING / SETTLED

Publishes:
  /imu/balance_cmd    (geometry_msgs/Vector3)  — corrections for wrist_balance_controller
  /balance_enabled    (std_msgs/Bool)           — gate for wrist_balance_controller
  /ball/is_centered       (std_msgs/Bool)          — True only when ball has been
                                                   continuously within stable_thresh
                                                   for centered_hold_time seconds.
                                                   Causes pose_test to advance immediately.
                                                   Distinct from /imu/is_stable (IMU-based).
  /ball/balance_error (geometry_msgs/Vector3)   — (ball_x, ball_y, magnitude) for debug
  /ball/pid_detail_flex (geometry_msgs/Vector3) — (P_flex, I_flex, D_flex) per tick
  /ball/pid_detail_roll (geometry_msgs/Vector3) — (P_roll, I_roll, D_roll) per tick
                                                   x+y+z = pre-clamp flex/roll cmd

Control law:
  error_x = ball_pos.x   (positive = ball right  → roll  cup left  → +wrist_roll)
  error_y = ball_pos.y   (positive = ball toward robot → flex forward → -wrist_flex)

  flex_cmd = +Kp_flex * error_y  - Kd_flex * imu_pitch_rate
  roll_cmd = +Kp_roll * error_x  - Kd_roll * imu_roll_rate

  imu_pitch_rate = angular_velocity.y from /imu/raw (rad/s) — true gyroscope rate.
  SIGN: D-term is SUBTRACTED so it opposes motion, providing true damping.
  When the cup is already tilting in the corrective direction (pitch_rate same
  sign as P command), D-term reduces total command magnitude — preventing overshoot.
  Adding D-term (wrong sign) would reinforce motion → positive feedback → oscillation.
  The IMU angle (from /imu/balance_error) is NOT used for D-term — that would
  act as a second P term biased by cup tilt, not a damping signal.

  The IMU term acts as derivative — it damps oscillation by sensing the
  direction the cup is already tilting before the ball reaches the edge.

Coordinate conventions (validated against balance_v1.yaml):
  wrist_roll  decreasing → tilt right,  increasing → tilt left
  wrist_flex  decreasing → tilt forward (away from robot)

  ball_pos.x  positive → ball right  → need roll left  → roll_cmd positive (+wrist_roll)
  ball_pos.y  positive → ball near   → need flex fwd   → flex_cmd negative (-wrist_flex)

Parameters:
  kp_flex         Camera P gain, flex axis         default: 0.3
  kp_roll         Camera P gain, roll axis         default: 0.3
  kd_flex         IMU D gain, flex axis            default: 0.1
  kd_roll         IMU D gain, roll axis            default: 0.1
  ki_flex         Integral gain, flex axis         default: 0.01
  ki_roll         Integral gain, roll axis         default: 0.01
  max_cmd         Max correction command (rad/s)   default: 0.3
  deadband        Ball position deadband (0..1)    default: 0.05
  stable_thresh   Ball within this = stable        default: 0.15
  publish_hz      Control loop rate (Hz)           default: 10.0
                  (limited by camera rate ~1.4Hz ONNX CPU)
  settle_delay    Seconds after SETTLED before PID default: 0.5
  camera_timeout  Seconds before camera stale      default: 2.0
  imu_timeout     Seconds before IMU stale         default: 0.5
  ball_lost_timeout  Seconds ball undetected before suspend  default: 1.0
  jiggle_amplitude   Cmd amplitude per axis during jiggle (rad/s) default: 0.02
  jiggle_start_delay Seconds lost before jiggle starts            default: 2.0
  jiggle_hz          Jiggle rate Hz — should match correction_hz  default: 1.0
                     4-phase circular: flex+, roll+, flex-, roll- over 4 steps.
                     Wrist controller hard limits naturally clamp any axis near its wall.
  attempt_timeout    Seconds before giving up balancing      default: 5.0
  dry_run         Log only, don't publish cmd      default: False
  use_imu         Use IMU derivative term          default: True

Usage:
  ros2 run writing_robot_control ball_balance_node

  # Dry run first to verify corrections:
  ros2 run writing_robot_control ball_balance_node --ros-args -p dry_run:=true

  # Tune gains:
  ros2 param set /ball_balance_node kp_flex 0.5
"""

import math
import time
import threading

import rclpy
from rclpy.node import Node
from geometry_msgs.msg import Point, Vector3
from sensor_msgs.msg import Imu, JointState
from std_msgs.msg import Bool, String


class BallBalanceNode(Node):

    def __init__(self):
        super().__init__('ball_balance_node')

        # Parameters
        self.declare_parameter('kp_flex',        0.3)
        self.declare_parameter('kp_roll',        0.3)
        self.declare_parameter('kd_flex',        0.02)  # conservative default — tune up carefully
        self.declare_parameter('kd_roll',        0.02)
        # d_term_source: where to read angular velocity for the D-term.
        #   'imu'    — /imu/raw angular_velocity (MPU-6050 gyro, 50Hz)
        #              KNOWN ISSUE: quantizes at 0.000133 rad/s/LSB — frozen
        #              at slow angular velocities typical of 1Hz corrections.
        #   'joints' — /balance/wrist_velocity (finite difference of joint_states, ~100Hz)
        #              More reliable for slow servo motion; directly measures
        #              what the servo did rather than cup vibration.
        #              Requires wrist_balance_controller_v25+.
        self.declare_parameter('d_term_source',  'joints')
        # Anti-windup decay factor applied when ball error changes sign (ball
        # crosses center axis). Decays the I-term to prevent windup from
        # pushing the ball further past center on overshoot.
        # 0.0 = full reset on sign change, 1.0 = no decay (disabled).
        # 0.2 = decay to 20% — recommended starting value.
        # Applied independently per axis: flex when error_y changes sign,
        # roll when error_x changes sign.
        self.declare_parameter('antiwindup_decay', 0.2)
        self.declare_parameter('ki_flex',        0.01)
        self.declare_parameter('ki_roll',        0.01)
        self.declare_parameter('max_cmd',        0.3)
        self.declare_parameter('deadband',       0.05)
        self.declare_parameter('stable_thresh',  0.15)
        self.declare_parameter('publish_hz',     15.0)
        self.declare_parameter('settle_delay',   0.5)
        self.declare_parameter('camera_timeout',    2.0)
        self.declare_parameter('imu_timeout',       0.5)
        self.declare_parameter('ball_lost_timeout', 1.0)
        self.declare_parameter('jiggle_amplitude',   0.02)  # rad/s per axis during jiggle
        self.declare_parameter('jiggle_start_delay', 2.0)   # seconds lost before jiggle starts
        self.declare_parameter('jiggle_hz',          1.0)   # jiggle rate — match correction_hz
        # Jiggle uses a 4-phase circular pattern: (+x,0), (0,+y), (-x,0), (0,-y).
        # This naturally avoids limit-slamming — any clamped axis just doesn't move
        # while the other axis still rocks the cup. No need to duplicate URDF limits.
        self.declare_parameter('attempt_timeout',     30.0)
        self.declare_parameter('centered_hold_time',  2.0)  # seconds ball must stay within stable_thresh
        self.declare_parameter('near_thresh',          0.30)  # near-center zone for summary stats
        self.declare_parameter('use_achievement',      True)  # scale commands by servo achievement ratio
        self.declare_parameter('achievement_alpha',    0.3)   # EMA weight for ratio update (0=frozen, 1=instant)
        self.declare_parameter('achievement_max_scale',3.0)   # max multiplier to prevent runaway
        self.declare_parameter('achievement_min_cmd',  0.003) # min |cmd| to avoid updating on HOLD steps

        # ki mode — three options, select via 'ki_mode' parameter:
        #   'ball'     — classic: accumulate ball_error × dt (standard PID integral)
        #   'servo'    — accumulate (commanded - achieved) servo delta per CORR step
        #                grows when servo underperforms, not just when ball is off-center
        #   'combined' — accumulate ball_error × (1 - achievement) × dt
        #                grows only when ball is wrong AND servo is underperforming
        #   'none'     — integral disabled (ki_flex=0 and ki_roll=0 still work as before)
        self.declare_parameter('ki_mode',  'ball')  # 'ball' | 'servo' | 'combined' | 'none'
        self.declare_parameter('ki_windup_limit', 0.5)  # clamp integral contribution to ±this
        self.declare_parameter('summary_hz',           1.0)   # rate of PID_SUMMARY log lines
        self.declare_parameter('dry_run',           False)
        self.declare_parameter('use_imu',           True)

        # State
        self._lock              = threading.Lock()

        # Camera
        self._ball_pos              = None   # Point (x, y, z)
        self._ball_time             = None   # monotonic timestamp of last fresh frame
        self._last_valid_ball_time  = None   # monotonic timestamp of last z>=0 detection

        # Attempt tracking
        self._pid_started_at        = None   # when PID became active this session

        # Initialize ball time to now so ball-lost timer doesn't fire immediately
        # on first detection after a long startup period
        self._last_valid_ball_time  = time.monotonic()

        # IMU
        self._imu_pitch         = 0.0   # rad — tilt angle from /imu/balance_error
        self._imu_roll          = 0.0   # rad
        self._imu_time          = None
        self._imu_pitch_rate    = 0.0   # rad/s — low-pass filtered angular velocity
        self._imu_roll_rate     = 0.0   # rad/s
        self._imu_raw_time      = None

        # Joint-state-derived angular velocity from /balance/wrist_velocity.
        # Published by wrist_balance_controller_v25+ at ~100Hz.
        # Used as D-term source when d_term_source='joints'.
        self._wrist_flex_vel    = 0.0   # d(wrist_flex_pos)/dt  rad/s
        self._wrist_roll_vel    = 0.0   # d(wrist_roll_pos)/dt  rad/s
        self._wrist_vel_time    = None  # monotonic time of last message
        # wrist_roll_pos removed — 4-phase jiggle doesn't need limit tracking
        # Low-pass filter coefficient for gyro smoothing.
        # alpha=0.3 means 30% new reading + 70% history — smooths noise
        # without adding significant lag at 50Hz IMU rate.
        self._gyro_alpha        = 0.3

        # Arm state
        self._arm_state         = 'MOVING'
        self._settled_at        = None
        self._pid_active        = False

        # Integrals
        self._integral_flex     = 0.0
        self._integral_roll     = 0.0
        self._integral_flex_servo  = 0.0   # ki_mode='servo'/'combined': undelivered flex
        self._integral_roll_servo  = 0.0   # ki_mode='servo'/'combined': undelivered roll

        # Previous error signs — used for anti-windup sign-change detection.
        # None until first valid ball reading.
        self._prev_error_x_sign = None   # sign of error_x on previous tick
        self._prev_error_y_sign = None   # sign of error_y on previous tick
        self._last_control_time = None

        # Servo achievement ratio — exponential moving average of (achieved/commanded).
        # When the servo only achieves 50% of commanded, next command is scaled up 2×.
        # Separate per axis since flex and roll have different load characteristics.
        self._flex_achievement  = 1.0   # starts at 1.0 (assume perfect)
        self._roll_achievement  = 1.0
        self._last_cmd_flex     = None  # most recent commanded delta
        self._last_cmd_roll     = None

        # Centered hold tracking — ball must stay within stable_thresh
        # continuously for centered_hold_time seconds before /ball/is_centered
        # is published True and the PID session ends.
        self._centered_since    = None

        # Jiggle state — alternating roll direction when ball is lost
        self._jiggle_phase      = 0  # 0-3 cycles through 4-phase circular pattern
        self._last_jiggle_time  = None  # monotonic time of last jiggle publish
        self._ball_lost_neutralized = False  # True once neutral cmd sent on ball-lost

        # 1Hz PID_SUMMARY accumulator — collects every /ball/position reading
        # at full 15Hz rate during active PID for accurate proximity stats.
        self._acc_magnitudes    = []
        self._acc_valid         = 0
        self._acc_invalid       = 0
        self._acc_near          = 0
        self._acc_tight         = 0

        # Publishers
        self._pub_cmd     = self.create_publisher(
            Vector3, '/imu/balance_cmd',    10)
        self._pub_enabled = self.create_publisher(
            Bool,    '/balance_enabled',    10)
        # Publishes True only when ball has been held at center for
        # centered_hold_time seconds — distinct from /imu/is_stable (IMU tilt).
        self._pub_centered = self.create_publisher(
            Bool,    '/ball/is_centered',   10)
        self._pub_err     = self.create_publisher(
            Vector3, '/ball/balance_error', 10)
        # Publishes full PID term breakdown for pid_logger and offline analysis.
        # Two messages per control tick — one for flex axis, one for roll axis.
        # Format: x=P_term  y=I_term  z=D_term
        # Total cmd = x + y + z (before max_cmd clamp).
        self._pub_pid_flex = self.create_publisher(
            Vector3, '/ball/pid_detail_flex', 10)
        self._pub_pid_roll = self.create_publisher(
            Vector3, '/ball/pid_detail_roll', 10)

        # Subscribers
        self.create_subscription(
            Point,      '/ball/position',
            self._ball_cb,       10)
        self.create_subscription(
            Vector3,    '/imu/balance_error',
            self._imu_cb,        10)
        # Subscribe to servo achievement feedback from wrist_balance_controller.
        # cmd_delta = what was commanded, achieved_delta = what the servo did.
        # Used to scale future commands so persistent servo underperformance
        # is compensated — true closed-loop PID spirit.
        self.create_subscription(
            Vector3, '/balance/cmd_delta',
            self._cmd_delta_cb, 10)
        self.create_subscription(
            Vector3, '/balance/achieved_delta',
            self._achieved_delta_cb, 10)

        # Subscribe to /imu/raw for angular velocity (true D-term signal).
        # imu_balance_node publishes: angular_velocity.x = dr (roll rate),
        #                             angular_velocity.y = dp (pitch rate).
        # This is opposite to ROS REP-103 — see _imu_raw_cb for full explanation.
        self.create_subscription(
            Imu, '/imu/raw',
            self._imu_raw_cb, 10)
        # Joint-state-derived wrist velocity from wrist_balance_controller_v25+.
        # x = d(wrist_flex_pos)/dt, y = d(wrist_roll_pos)/dt  (rad/s, ~100Hz).
        # Used as D-term source when d_term_source='joints'.
        self.create_subscription(
            Vector3, '/balance/wrist_velocity',
            self._wrist_vel_cb, 10)
        self.create_subscription(
            String,     '/arm_state',
            self._arm_state_cb,  10)
        self.create_subscription(
            JointState, '/joint_states',
            self._joint_state_cb, 10)

        # Control timer
        hz = self.get_parameter('publish_hz').value
        self._timer = self.create_timer(1.0 / hz, self._control_loop)

        # 1Hz summary timer — logs PID_SUMMARY during active sessions
        summary_hz = self.get_parameter('summary_hz').value
        self.create_timer(1.0 / summary_hz, self._summary_loop)

        self.get_logger().info('ball_balance_node started.')
        self.get_logger().info(
            'Subscriptions: /ball/position  /imu/balance_error  /imu/raw  /arm_state')
        self.get_logger().info(
            f'D-term: kd_flex={self.get_parameter("kd_flex").value}  '
            f'kd_roll={self.get_parameter("kd_roll").value}  '
            f'use_imu={self.get_parameter("use_imu").value}  '
            f'(angular velocity from /imu/raw, NOT tilt angle)')
        self.get_logger().info(
            'Publishes: /imu/balance_cmd  /balance_enabled  /ball/is_centered')
        if self.get_parameter('dry_run').value:
            self.get_logger().info(
                'DRY RUN — corrections logged but NOT published to /imu/balance_cmd')

    # Callbacks

    def _ball_cb(self, msg: Point):
        """Camera ball position callback.

        Accumulates every reading into the 1Hz PID_SUMMARY stats.
        Tracks centered_hold_time to determine when to publish /ball/is_centered.
        """
        with self._lock:
            if msg.z < 0:
                # z=-1: ball not detected. Update ball_time so timeout logic
                # still fires correctly, but reset centered_since — the ball
                # cannot be considered at center if we cannot see it.
                self._ball_time     = time.monotonic()
                self._centered_since = None
                if self._pid_active:
                    self._acc_invalid += 1
                return
            self._ball_pos             = msg
            self._ball_time            = time.monotonic()
            self._last_valid_ball_time = time.monotonic()
            # Ball redetected — reset jiggle and neutral-cmd state so next
            # ball-lost event starts fresh.
            self._ball_lost_neutralized = False
            self._last_jiggle_time      = None
            self._jiggle_phase          = 0

            if self._pid_active:
                import math as _m
                mag = _m.sqrt(msg.x**2 + msg.y**2)
                st  = self.get_parameter('stable_thresh').value
                nt  = self.get_parameter('near_thresh').value
                self._acc_magnitudes.append(mag)
                self._acc_valid += 1
                if mag < nt: self._acc_near  += 1
                if mag < st: self._acc_tight += 1

    def _imu_cb(self, msg: Vector3):
        """IMU balance error callback (pitch, roll from imu_balance_node)."""
        with self._lock:
            self._imu_pitch = msg.x
            self._imu_roll  = msg.y
            self._imu_time  = time.monotonic()

    def _cmd_delta_cb(self, msg: Vector3):
        """Receive the commanded flex/roll delta from the previous CORR step."""
        with self._lock:
            self._last_cmd_flex = msg.x
            self._last_cmd_roll = msg.y

    def _achieved_delta_cb(self, msg: Vector3):
        """Receive achieved flex/roll delta and update achievement ratios.

        Updates an exponential moving average of achieved/commanded per axis.
        Only updates when the commanded delta is above a minimum threshold
        to avoid dividing by near-zero and to ignore HOLD steps.
        """
        with self._lock:
            if not self.get_parameter('use_achievement').value:
                return
            alpha   = self.get_parameter('achievement_alpha').value
            min_cmd = self.get_parameter('achievement_min_cmd').value

            ki_mode     = self.get_parameter('ki_mode').value
            windup_lim  = self.get_parameter('ki_windup_limit').value
            ki_flex     = self.get_parameter('ki_flex').value
            ki_roll     = self.get_parameter('ki_roll').value

            if self._last_cmd_flex is not None:
                cmd_f = abs(self._last_cmd_flex)
                act_f = abs(msg.x)
                if cmd_f >= min_cmd:
                    ratio_f = min(act_f / cmd_f, 2.0)
                    self._flex_achievement = ((1 - alpha) * self._flex_achievement +
                                              alpha * ratio_f)
                    self._flex_achievement = max(0.05, self._flex_achievement)
                    # servo ki — accumulate undelivered flex displacement
                    if ki_mode in ('servo', 'combined') and ki_flex > 0:
                        undelivered_f = self._last_cmd_flex - msg.x  # signed gap
                        self._integral_flex_servo += undelivered_f
                        self._integral_flex_servo = max(
                            -windup_lim / max(ki_flex, 1e-6),
                            min(windup_lim / max(ki_flex, 1e-6),
                                self._integral_flex_servo))
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

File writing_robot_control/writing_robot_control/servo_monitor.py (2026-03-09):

#!/usr/bin/env python3
"""
Dynamixel Continuous Servo Monitor - CORRECTED
Monitors servos periodically to catch intermittent failures

FIXED: Now correctly handles XL430 vs XL330 differences
- XL430 (IDs 1, 2): Reads Present Load (%), NOT Current
- XL330 (IDs 3-6): Reads Present Current (mA)

Usage:
  python3 servo_monitor.py --interval 5 --duration 300
  python3 servo_monitor.py --interval 10 --csv monitor.csv
  
Useful for:
  - Catching thermal issues (temperature rising over time)
  - Voltage sag detection (voltage dropping under load)
  - Intermittent communication failures
  - Degradation patterns
"""

from dynamixel_sdk import *
import time
import argparse
import csv
from datetime import datetime
import signal
import sys

# Servo configuration with types
SERVOS = {
    1: {'name': 'shoulder_pan', 'model': 'XL430-W250', 'type': 'XL430'},
    2: {'name': 'shoulder_lift', 'model': 'XL430-W250', 'type': 'XL430'},
    3: {'name': 'elbow_flex', 'model': 'XL330-M288', 'type': 'XL330'},
    4: {'name': 'wrist_flex', 'model': 'XL330-M288', 'type': 'XL330'},
    5: {'name': 'wrist_roll', 'model': 'XL330-M288', 'type': 'XL330'},
    6: {'name': 'pen_holder', 'model': 'XL330-M077', 'type': 'XL330'}
}

# Protocol 2.0
PROTOCOL_VERSION = 2.0

# Control table addresses (Protocol 2.0)
# Common addresses
ADDR_TORQUE_ENABLE = 64
ADDR_PRESENT_POSITION = 132
ADDR_PRESENT_TEMPERATURE = 146
ADDR_PRESENT_INPUT_VOLTAGE = 144
ADDR_HARDWARE_ERROR_STATUS = 70

# Address 126 is DIFFERENT for each servo type:
# XL430: Present Load (percentage)
# XL330: Present Current (mA)
ADDR_126_XL430_LOAD = 126      # Present Load for XL430
ADDR_126_XL330_CURRENT = 126   # Present Current for XL330

# Torque values
TORQUE_ENABLE = 1
TORQUE_DISABLE = 0

# Port
DEVICENAME = '/dev/ttyOpenRB'
BAUDRATE = 1000000

# Global for clean shutdown
running = True

def signal_handler(sig, frame):
    """Handle Ctrl+C gracefully."""
    global running
    print('\n\nShutdown requested...')
    running = False

def enable_torque_all(port_handler, packet_handler, servo_ids):
    """Enable torque on all servos."""
    print("\nEnabling torque on all servos...")
    
    success_count = 0
    for servo_id in servo_ids:
        result, error = packet_handler.write1ByteTxRx(
            port_handler, servo_id, ADDR_TORQUE_ENABLE, TORQUE_ENABLE
        )
        
        if result == COMM_SUCCESS and error == 0:
            print(f"  ✓ Servo #{servo_id} ({SERVOS[servo_id]['name']}): Torque enabled")
            success_count += 1
        else:
            print(f"  ❌ Servo #{servo_id} ({SERVOS[servo_id]['name']}): Failed to enable torque")
            if result != COMM_SUCCESS:
                print(f"     Error: {packet_handler.getTxRxResult(result)}")
            if error != 0:
                print(f"     Packet Error: {packet_handler.getRxPacketError(error)}")
    
    print(f"\nTorque enabled on {success_count}/{len(servo_ids)} servos")
    return success_count == len(servo_ids)

def disable_torque_all(port_handler, packet_handler, servo_ids):
    """Disable torque on all servos (for safety at shutdown)."""
    print("\nDisabling torque on all servos...")
    
    for servo_id in servo_ids:
        result, error = packet_handler.write1ByteTxRx(
            port_handler, servo_id, ADDR_TORQUE_ENABLE, TORQUE_DISABLE
        )
        
        if result == COMM_SUCCESS and error == 0:
            print(f"  ✓ Servo #{servo_id} ({SERVOS[servo_id]['name']}): Torque disabled")
        else:
            print(f"  ⚠️ Servo #{servo_id} ({SERVOS[servo_id]['name']}): Failed to disable torque")
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

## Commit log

2025-10-21 switch to koch physical frame
    [koch_controllers.yaml, koch_writing_arm.urdf]
2025-10-25 new approach for koch_v11
    [koch_v11_arm.urdf, koch_v11_controllers.yaml, koch_v11_robot_arm.urdf]
2025-10-26 small changes to deal with initial position and ground
    [koch_v11_arm.urdf]
2025-11-01 real robot changes
    [koch_v11_arm_real.urdf, koch_v11_controllers_real.yaml, koch_v11_robot_arm.urdf.xacro]
2025-11-07 hardware tuning
    [koch_v11_arm_real.urdf, koch_v11_controllers_real.yaml]
2025-11-18 physical tuning
    [koch_v11_arm_real.urdf]
2025-11-21 update with the base servo now a XL430
    [koch_v11_arm_real.urdf]
2025-11-21 initial STL setup for RVIZ
    [Follower_Base.STL, Follower_Shoulder_Rotation.STL, fr12_s102.stl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]
2025-11-21 STL binary conversion as needed by RVIZ
    [Follower_Base_binary.stl, Follower_Shoulder_Rotation_binary.stl, koch_v11_arm_real.urdf]
2025-11-21 add rest of binary stls for the attachments
    [Follower_Elbow_To_Wrist_Extension_binary.stl, Follower_Elbow_To_Wrist_binary.stl, Follower_Gripper_Moving_Part_binary.stl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]
2025-11-24 temp fixes to work around servo failures and being one servo down
    [koch_v11_arm_real.urdf, koch_v11_controllers_real.yaml]
2025-11-26 freecad intermediate work
    [robot_arm.FCStd]
2025-11-27 update to arm
    [robot_arm.FCStd]
2025-11-30 update to data
    [robot_arm.FCStd]
2025-11-30 replaced 6th servo and worked up demo
    [koch_controllers.yaml, koch_v11_arm_real.urdf, koch_v11_controllers_real.yaml]
2025-11-30 some more
    [koch_writing_arm.urdf]
2025-12-01 robot pieced together in freecad
    [robot_arm.FCStd]
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2025-12-01 first attempt to integrate freecad connections
    [koch_v11_arm_real.urdf]
2025-12-01 small fix
    [koch_v11_arm_real.urdf]
2025-12-01 fix mesh path issue
    [koch_v11_arm_real.urdf]
2025-12-01 relfecting extraction fix
    [koch_v11_arm_real.urdf]
2025-12-02 additional fixes
    [koch_v11_arm_real.urdf]
2025-12-02 Enhance README with project goals and tasks
    Expanded the project description to include goals and tasks related to robotic arm development.
2025-12-04 new approach to fix rviz display of robot
    [robot_arm.urdf]
2025-12-04 updated freecad documents with initial new approach
    [robot_arm.FCStd]
2025-12-06 freecad changes for zero rotation
    [robot_arm.v3.FCStd]
2025-12-06 intermediate changes
    [robot_arm.urdf]
2025-12-06 elbow flex fixed in display
    [robot_arm.urdf]
2025-12-08 working on hand_link
    [robot_arm.v3.FCStd, scratch.FCStd]
2025-12-08 hand link donegit add writing_robot_description/urdf/robot_arm.urdf
    [robot_arm.urdf]
2025-12-08 pen_link working
    [robot_arm.urdf]
2025-12-08 reflect display changes to the real robot urdf
    [koch_v11_arm_real.urdf]
2025-12-09 intermediate change
    [koch_v11_arm_real.urdf]
2025-12-10 next try
    [robot_arm.urdf]
2025-12-10 axis change
    [robot_arm.urdf]
2025-12-10 changes to support zero position
    [robot_arm.v3.FCStd, robot_arm_v4.FCStd]
2025-12-10 fixed thumb
    [robot_arm.urdf]
2025-12-10 reflecting fix into real robot urdf
    [koch_v11_arm_real.urdf]
2025-12-11 adjustments to two joint angles
    [koch_v11_arm_real.urdf]
2025-12-13 fixed thumb overreach
    [koch_v11_arm_real.urdf]
2025-12-16 pose test program to validate poses
    [koch_v11_arm_real.urdf, koch_v11_controllers_real.yaml]
2025-12-16 reading urdf to get limits and fix to validation
    [pose_test.py]
2025-12-16 cleaned up transmission matrix for joint 3
    [koch_v11_arm_real.urdf]
2025-12-17 reflect latest real robot urdf to display-only version
    [robot_arm.urdf]
2025-12-17 fix for base joint 1 rotating the wrong direction in rviz
    [koch_v11_arm_real.urdf]
2025-12-17 fix for wrist roll being off by 90 degrees in rviz from real robot
    [koch_v11_arm_real.urdf]
2025-12-17 one more tweak to that fix
    [koch_v11_arm_real.urdf]
2025-12-17 fix for wrong angle for shoulder lift
    [koch_v11_arm_real.urdf]
2025-12-18 calculations and additions to urdf for inertial properties
    [koch_v11_arm_real.urdf]
2025-12-18 collision update in urdf
    [koch_v11_arm_real.urdf]
2025-12-19 load testing tool and pose_test improvements
    [koch_v11_arm_real.urdf]
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2025-12-22 fixes for being able to support pulling temp, current, etc in ros
    [koch_v11_arm_real.urdf]
2025-12-23 some bug fixes and addition of new delivery pose set v1.0
    [koch_v11_arm_real.urdf]
2025-12-24 Document usage and output for Servo Monitor utility
    Added detailed instructions and output examples for running the Servo Monitor utility, including warnings and monitoring summary.
2025-12-24 Add servo range of motion test example
    Added a servo range of motion test example with detailed logging output.
2025-12-24 Enhance pose_test documentation with examples and parameters
    Added sections for parameters, pose sequence examples, servo range of motion tests, validation errors, and FAQ to the documentation.
2025-12-25 Enhance documentation for Servo Monitor utility
    Added a Table of Contents and updated parameters section.
2025-12-26 Enhance load test analysis documentation
    Expanded the load test analysis documentation to include detailed parameters, example invocations, and additional features such as torque predictions and CSV output.
2025-12-26 Enhance documentation for Servo Monitor utility
    Expanded the description of the servo monitor utility and added usage examples.
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2026-01-10 Update README with power monitoring information
    Added section on power monitoring using INA219 sensors.
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2026-01-12 fix for negative current summary
    [pose_test.py]
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2026-01-17 Enhance hardware setup documentation with additional notes
    Added detailed notes on hardware setup, including power supply configurations and cable length issues for servos.
2026-01-17 Revise cable length issues for servo setup
    Updated cable length issues section to clarify the use of a power adapter and the implications of cable gauge on servo performance.
2026-01-18 Update hardware setup documentation with overview
    Added detailed hardware overview for the Kock v1.1 follower arm, including specifications and components used.
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2026-01-19 Update 3D printing section in hardware setup documentation
    Added details on 3D printing options and resources for robot arm components.
2026-01-19 Revise hardware setup documentation for clarity
    Updated cable length issues and added image for clarity. Included learnings about the base link design.
2026-01-25 freecad files
    [robot_arm.FCStd, robot_arm.v2.FCStd, robot_arm.v3.FCStd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]
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2026-02-02 Update hardware setup documentation with additional notes
    Added notes on INA226 sensor integration, servo power configurations, and cable length issues affecting range of motion.
2026-02-02 fix for ina226 voltage and current readings
    [read_ina219_ina226.ino]
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2026-02-09 Revise digital twin documentation for clarity and detail
    Updated the documentation for creating a high-fidelity digital twin, enhancing clarity and correcting phrasing throughout. Added details on the importance of proper alignment in CAD assemblies and provided clearer instructions for the FreeCAD process.
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2026-02-11 Fix formatting of power monitoring section in README
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2026-02-11 Fix link to Power Monitoring documentation
    Corrected the link to the Power Monitoring documentation.
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2026-02-25 clean up urdf files
    [koch_v11_arm_sim.urdf, koch_v11_arm_simple_sim.urdf, koch_v11_robot_arm.urdf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]
2026-02-25 simplified the display launch code
    [koch_v11_arm_sim.urdf]
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2026-03-09 changes to support imu plus power_monitor_node bug fix
    [koch_v11_arm_real.urdf]
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2026-03-21 urdf update for balance exercise
    [koch_v11_arm_real_for_balance.urdf]
2026-03-21 tune the model to reflect right order
    [koch_v11_arm_real_for_balance.urdf]
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2026-04-03 fixes for running camera on orin nano
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2026-04-05 some fixes for camera
2026-04-06 unified pid on vision and imu plus other tuning of urdf
    [koch_v11_arm_real_for_balance.urdf]
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2026-04-20 more tuning of the system for balance
    [controllers.yaml, koch_v11_controllers_real.yaml]
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2026-04-29 fix for slow start to imu sensor
    [imu_balance_node.py]
2026-04-29 imu fixes for CP210x chip quirks
    [imu_balance_node.py]
2026-04-29 some fixes for humble->jazzy dds
    [pose_test.py]
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2026-05-08 fix for ball balance
    [ball_balance_node.py]
2026-05-09 some parameter default and docuemntation fixes
    [ball_balance_node.py]
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2026-05-30 fix for jiggle storm
    [ball_balance_node.py]
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2026-06-09 start tuning of XL430 shoulder lift to get rid of jitter
    [servo_config_node.py]
2026-06-21 cup v3 stl, freecad doc, and image
    [cup.v3-Body.stl, cup.v3.FCStd]
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2026-10-24 fix fallback to profile urdf for pose_test.py
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2026-11-05 Add balance_logic unit tests, including three currently failing bug tests
    - test_new_session_does_not_inherit_previous_step
    - test_deltas_are_in_command_units_with_negative_scale
    - test_ball_never_seen_in_attempt_counts_from_attempt_start
    Each reproduces a fault seen in the 2026-11-04 SO-ARM101 run; the fixes
    follow in separate commits.
    Claude-Session: https://claude.ai/code/session_01Qx9mKxEegUE5o6ZQARtUpg
2026-11-05 wrist_balance_controller: forget the previous step when balancing restarts
    The achieved delta was measured against the previous session's last CORR
    target. After a pose change that reported the whole move as achieved (pose
    11 on 2026-11-04: about +0.57 rad), which wound ball_balance_node's servo
    integral to -0.646 in one step and held the flex correction reversed for
    the whole attempt. WristAxis.begin() now clears the previous step.
    Fixes test_new_session_does_not_inherit_previous_step.
    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
2026-11-05 wrist_balance_controller: publish cmd_delta and achieved_delta in command units
    ball_balance_node integrates (cmd_delta - achieved_delta) into its servo
    integral and adds it to the command it sends, before flex_scale/roll_scale
    are applied. The wrist controller published both in joint units, after the
    scale, so with flex_scale = -1 (SO-ARM101) an undershooting servo pushed the
    integral against the command. Both are now divided by the axis scale.
    The Koch (scale +1) is unaffected. pid_logger's cmd_delta_*/achieved_delta_*
    columns change sign for axes with a negative scale.
    Fixes test_deltas_are_in_command_units_with_negative_scale.
    Cla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
2026-11-05 ball_balance_node: treat a ball not found after a pose change as lost
    On MOVING the node cleared last_valid_ball_time but kept the previous pose's
    ball position. If the detector never found the ball after the move, the
    ball-lost check (which needed last_valid_ball_time) never fired and the PID
    ran on the stale position: pose 10 on 2026-11-04 balanced for 19 s on
    (+0.144, +0.546) with 0 valid frames, driving flex to its hard limit.
    - ball_lost_duration() falls back to the attempt start time.
    - MOVING also clears the ball position; the control loop waits (no command)
    until the ball is detected or ball_lost_timeout suspends the PID and
    starts the jiggle.
    Fixes test_ball_never_seen_in_atte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
2026-11-05 fixes to analysis scripts for feetech servos
2026-11-06 Extract ball_balance_node's control law into balance_logic
    Behavior-preserving: deadband, the ki_mode='ball' integral step (including
    its deadband decay and anti-windup clamp), the zero-crossing test for the
    sign-change decay, the ki_mode integral selection and the per-axis P/I/D
    law move into ROS-free functions (apply_deadband, ball_integral_step,
    crossed_center, error_sign, select_integrals, pid_axis) that the node calls.
    Checked against the original inline code on 20000 random inputs.
    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
2026-11-06 ball_balance_node: keep only the servo integral; remove ki_mode
    The I term now always accumulates the undelivered wrist delta (commanded -
    achieved per CORR step), which is what ki_mode: servo did and what both
    arms' balance params use. Removed:
    - ki_mode 'ball' (ball error x dt): the ball error is already integrated,
    since each command is a step added to the wrist position, so a second
    integral of it tends to overshoot;
    - ki_mode 'combined': documented but never implemented (behaved as 'ball');
    - ki_mode 'none': ki_flex = ki_roll = 0 does the same.
    With them go the ki_mode parameter, the ball integrals, their clamp and
    deadband decay, and the control-step clock they needed. The CMD lo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
2026-11-06 Add control-law unit tests
    test/test_pid_law.py: P sign on each axis, D opposing the wrist rate,
    I = ki * integral, clamp to max_cmd, deadband, the servo integral
    (sign, accumulation, overshoot, windup clamp, ki = 0) and the
    zero-crossing trigger for the sign-change decay.
    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
